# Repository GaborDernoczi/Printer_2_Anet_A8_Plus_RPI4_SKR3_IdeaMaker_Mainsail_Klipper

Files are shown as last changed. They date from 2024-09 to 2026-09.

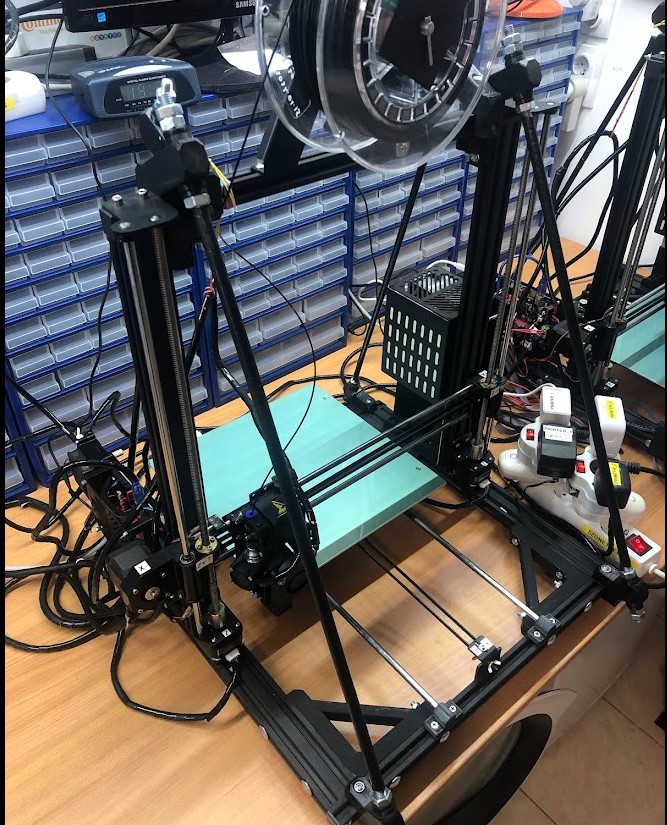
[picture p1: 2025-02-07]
Pictures/Anet_A8_Plus_Printer2_RPI4_SKR3.jpg

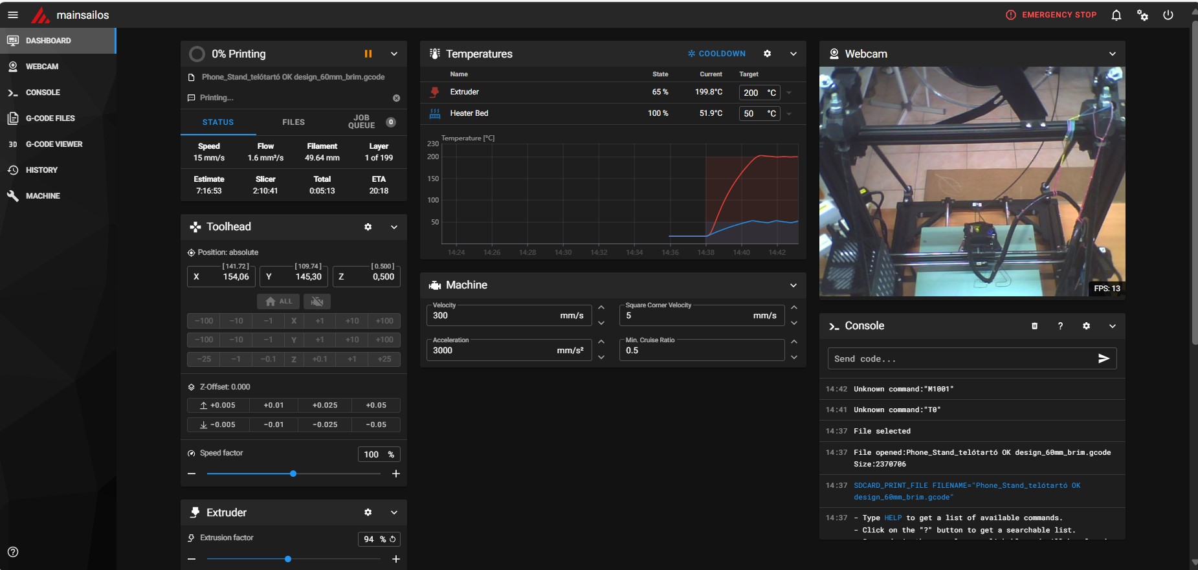
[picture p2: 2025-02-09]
Pictures/Anet_A8_Plus_Printer2_RPI4_Mainsailos.jpg

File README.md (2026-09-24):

# Printer #2 — Anet A8 Plus → Klipper / MainsailOS Conversion

> Converting an Anet A8 Plus from **Marlin + OctoPrint** to **Klipper + Mainsail**, running on a
> Raspberry Pi 4B with a BigTreeTech SKR 3 controller, sliced with the **latest version of
> IdeaMaker** — and fully operable remotely.

This repository is a complete build log and configuration archive. The goal is that the printer
can be **rebuilt from scratch using only the files in this repo**.

---

## Table of Contents

1. [Project Background](#1-project-background)
2. [System Architecture](#2-system-architecture)
3. [Remote Operation](#3-remote-operation)
4. [Hardware](#4-hardware)
5. [Repository Structure](#5-repository-structure)
6. [Rebuild Guide](#6-rebuild-guide)
7. [Key Configuration Values](#7-key-configuration-values)
8. [IdeaMaker Slicer Setup](#8-ideamaker-slicer-setup)
9. [Calibration Results](#9-calibration-results)
10. [Printed Upgrade Parts](#10-printed-upgrade-parts)
11. [References](#11-references)

---

## 1. Project Background

Printer #1 originally ran **Marlin firmware with OctoPrint**. It suffered from recurring problems:

- Inconsistent **bed adhesion**
- Unstable **temperature control**
- Poor and inconsistent print quality, leading to frequent failed prints
- Repeated bed-height calibration did not solve the underlying issues

The printer now runs independently on its own Raspberry Pi and Mainsail instance. The Pi is
reachable on the local network as `pi1` (the presentation records `192.168.0.127` as the example
address; use the current DHCP reservation in your network).

### Outcome

After the conversion the printer has been running **stably**, with no further adhesion or
temperature problems, and significantly improved print performance. Dimensional accuracy was then
dialled in through a documented calibration cycle (see section 9), and the whole workflow — from
slicing to starting the print — became operable without physically touching the machine
(see section 3).

---

## 2. System Architecture

```mermaid
flowchart LR
    PC["Workstation<br/>IdeaMaker slicer"]
    WEB["Browser<br/>Mainsail UI"]
    RPI["Raspberry Pi 4B<br/>MainsailOS<br/>hostname: pi1"]
    KLIPPY["Klippy host process<br/>+ Moonraker API"]
    SKR["BTT SKR 3<br/>STM32H743<br/>TMC2209 x4"]
    HW["Steppers · Heaters<br/>Thermistors · BLTouch"]

    PC -->|upload .gcode| WEB
    WEB -->|HTTP / WebSocket :7125| RPI
    RPI --- KLIPPY
    KLIPPY -->|USB serial| SKR
    SKR --> HW
```

**Division of labour:** the Raspberry Pi does all motion planning, kinematics, pressure advance
and bed-mesh compensation. The SKR 3 only executes pre-computed step timings. This is why the
Klipper configuration lives entirely in `printer.cfg` on the Pi, and the firmware on the board
almost never needs reflashing.

---

## 3. Remote Operation

A core goal of the conversion was **full remote control**: the entire chain — workstation, printer
power, slicing, print start and supervision — can be driven without being in the same room as the
machine.

```mermaid
flowchart TD
    U["Operator<br/>(remote / voice)"]
    ALEXA["Amazon Alexa"]
    SON["Sonoff 230 V smart socket"]
    NANO["Arduino Nano<br/>(powered from the socket, 5 V)"]
    REL["Relay module<br/>momentary contact closure"]
    BTN["PC front-panel<br/>PWR_SW header"]
    PCX["Workstation PC<br/>powers on"]
    PWR["Remote mains switch<br/>printer + Raspberry Pi"]
    PRN["Printer + Raspberry Pi<br/>power on"]
    SLICE["IdeaMaker<br/>slice + export G-code"]
    MS["Mainsail<br/>upload + start print"]
    CAM["Webcam via crowsnest<br/>live supervision"]

    U --> ALEXA --> SON --> NANO --> REL --> BTN --> PCX --> SLICE --> MS
    U --> PWR --> PRN --> MS
    MS --> CAM --> U
```

### Remote power-on of the workstation

The PC is **not** started with Wake-on-LAN. Instead it is started by physically pressing its own
power button, electrically:

1. The operator issues a switch-on command to **Amazon Alexa** (voice or app).
2. Alexa switches on a **Sonoff 230 V smart socket**.
3. The socket feeds an **Arduino Nano**, which therefore boots the moment mains power appears.
4. On start-up the Nano drives a **relay module**.
5. The relay **closes the contacts of the PC's power button** (the `PWR_SW` front-panel header),
   which boots the workstation.

The advantage over Wake-on-LAN is that it is completely independent of the BIOS, the network card,
the operating system and Windows fast-startup. It works even after a full power loss, because it
emulates the same physical action a person would perform.

> **Important:** the relay must produce a **short pulse (roughly 0.3–1 s), not a permanent
> closure.** A continuously held power button is interpreted by the PC as a forced shutdown
> request. The Nano sketch should therefore pulse the relay once after boot and then leave it
> open.

### What each piece does

| Capability | How | Result |
|---|---|---|
| **Start the PC remotely** | Alexa → Sonoff 230 V socket → Arduino Nano (5 V) → relay module → PC power-button contacts | The slicing machine is brought up on demand; no need to leave it running |
| **Start the printer remotely** | Remotely switchable mains power feeding the printer and the Pi | The machine stays powered down between jobs and is energised only when a print is planned |
| **Slice remotely** | Remote desktop onto the workstation, IdeaMaker running there | The slicer profile lives on one machine only — no profile drift |
| **Upload and start** | Mainsail web UI / Moonraker API on port 7125 | Upload `.gcode`, start, pause, cancel, tune live |
| **Watch the print** | `crowsnest` webcam stream embedded in Mainsail | Visual confirmation of the first layer and of progress |
| **Timelapse** | `moonraker-timelapse` (`timelapse.cfg`) | Automatic video of completed prints |

### Why the printer is kept unpowered between jobs

Leaving a heated-bed printer permanently energised is the main fire-risk scenario in a home
workshop. Putting the mains feed on a remotely switchable outlet makes the **default state "off"**,
and power is applied only for the duration of a supervised job. The Raspberry Pi boots in under a
minute, so there is no practical downside.

### Requirements and safety rules

- **Pulse, do not hold, the PC power button.** The Arduino Nano must close the relay only
  momentarily after boot; a permanently closed contact forces the PC off instead of on.
- **Use the relay contacts only as a dry switch** across the `PWR_SW` header. Never feed the
  Arduino's 5 V into the header — the relay must isolate the two circuits.
- **Set the PC BIOS "restore on AC power loss" option to "stay off"**, otherwise the machine may
  boot on its own and the relay pulse will shut it down again.
- **Give the Pi and the PC reserved DHCP leases** so their addresses never move.
- **Do not expose Mainsail or Moonraker directly to the internet.** Moonraker has no
  authentication model suitable for public exposure; `moonraker.conf` in this repo trusts private
  LAN ranges only. Reach the printer from outside over a **VPN**.
- **Never start a heater without a working camera view.** Remote power-on combined with an
  unattended thermal fault is precisely the combination to avoid.
- **Always verify the first layer on the camera** before leaving the print unattended.
- Keep a **physically reachable power cut-off**. A remote switch must never be the only way to
  de-energise the printer.

---

## 4. Hardware

| Component | Part | Notes |
|---|---|---|
| Base printer | Anet A8 Plus | 300 × 300 × 300 mm build volume |
| Frame | Reinforced aluminium-extrusion conversion | Diagonal bracing + corner gussets (AM8-style). Replaces the original acrylic frame. |
| Controller | BigTreeTech **SKR 3** | STM32H743 |
| Stepper drivers | **TMC2209** ×4 | UART mode |
| Host | **Raspberry Pi 4B** | MainsailOS |
| Hotend | **Volcano V6** | Custom mounting solution |
| Probe | **BLTouch / 3D Touch** | Automatic bed mesh levelling |
| Power | **External MOSFET** for the heated bed | Offloads bed current from the board |
| Mains control | **Remotely switchable outlet** (smart plug / relay) | Allows the printer to be powered up and down remotely — see section 3 |
| Camera | USB / Pi camera via **crowsnest** | Live view for remote supervision; timelapse support included |
| Slicer host | Workstation PC, started by the Sonoff + Arduino Nano + relay circuit | Runs the latest IdeaMaker; can be started remotely — see section 3 |
| PC remote start | **Sonoff 230 V smart socket** + **Arduino Nano** + **relay module** | Alexa-triggered; the relay shorts the PC power-button contacts |

> **Verify the MCU on the board before building Klipper.** This build uses the STM32H743 variant
> of the SKR 3 and therefore requires the H743 firmware target described below.

---

## 5. Repository Structure

| Path | Contents |
|---|---|
| `Configuration_Mainsail_Klipper/` | `printer.cfg`, `moonraker.conf`, `mainsail.cfg`, `crowsnest.conf`, `sonar.conf`, `timelapse.cfg` — the working Klipper/Moonraker config set |
| `Calibration/` | Calibration models and the `Klipper Calibrations.xlsx` workbook |
| `IdeaMaker_Profiles/` | `Printer2_ANET_A8_Plus_RPI4_SKR3_Ideamaker_Profile.bin`, Start G-code and End G-code |
| `IdeaMaker_Models/` | `.idea` project files and `.3mf` models actually printed on this machine |
| `Consoles_and_Parts/` | STL files for printed upgrade parts (belt tensioners, fan duct, Pi case, spacers) |
| `Pictures/` | Build and diagnostic photos (BLTouch wiring, external MOSFET, printer render, test prints) |
| `SKR3_User manual/` | BigTreeTech SKR 3 user manual PDF |
| `Mainsail and klipper RPI4 SKR3.pptx` | Step-by-step conversion presentation |

---

## 6. Rebuild Guide

### Step 1 — Flash MainsailOS onto the SD card

1. Install **Raspberry Pi Imager**.
2. Choose **Other specific-purpose OS → 3D printing → MainsailOS (64-bit)**.
3. In the Imager's advanced settings, configure **before** writing:
   - **Hostname** — must be unique per printer (this build uses `pi1`)
   - **Wi-Fi SSID + password**
   - **SSH enabled**, username and password
4. Write the image and boot the Pi.

> **Running two printers?** Give each Pi a distinct hostname *and* a reserved (static) DHCP lease
> in the router. Two Pis = two independent Mainsail instances. Mixing them up is the most common
> cause of "I edited the config and nothing changed".

### Step 2 — Build the Klipper firmware for the SKR 3

SSH into the Pi (e.g. with **Tera Term** or any SSH client) and run:

```bash
cd ~/klipper
make menuconfig
```

Select:

| Option | Value |
|---|---|
| Micro-controller Architecture | `STMicroelectronics STM32` |
| Processor model | `STM32H743` |
| Bootloader offset | `128KiB bootloader` |
| Clock reference | `25 MHz crystal` |
| Communication interface | `USB (on PA11/PA12)` |

Then build:

```bash
make clean
make
```

The output is `~/klipper/out/klipper.bin`.

### Step 3 — Flash the board

`make flash` is not used for this SKR 3 setup. Flash via SD card instead:

1. Download `out/klipper.bin` from the Pi (e.g. with **FileZilla** over SFTP).
2. Rename it to **`firmware.bin`**.
3. Copy it to a FAT32 SD card and insert it into the SKR 3.
4. Power the SKR 3 and wait for the board to finish flashing.
5. Power-cycle the board.
6. **Verification:** the file on the SD card is renamed to `firmware.cur`. If it still says
   `firmware.bin`, the flash did not happen — check the card format, the filename and the jumper.

### Step 4 — Find the MCU serial ID

On the Pi:

```bash
ls /dev/serial/by-id/*
```

Copy the returned path into the `[mcu]` section of `printer.cfg`. Example from this build:

```ini
[mcu]
serial: /dev/serial/by-id/usb-Klipper_stm32h743xx_38003A001751313238353730-if00
```

> This ID is **unique to your board** — it will not match the value in this repo. You must
> replace it.

### Step 5 — Upload the configuration

Copy `Configuration_Mainsail_Klipper/printer.cfg` to the Pi, either through the Mainsail
web UI (**Machine** tab) or over SFTP to `~/printer_data/config/`.

Then check `moonraker.conf` — the `[authorization] trusted_clients` list must include your LAN
subnet, otherwise the web UI will refuse the connection.

Restart Klipper from Mainsail (`FIRMWARE_RESTART`).

### Step 6 — Wire and enable the BLTouch

Wiring photos: `Pictures/3d_touch.jpg`, `3d_touch_2.jpg`, `3d_touch_pins.jpg`.

The probe replaces the Z endstop — note that `[stepper_z]` uses
`endstop_pin: probe:z_virtual_endstop`.

### Step 7 — Safety checks before the first print

Run these **in order**, and keep a hand on the power switch:

```gcode
# 1. Thermistors read plausible room temperature?      -> check Mainsail dashboard
# 2. Does the probe deploy/stow?
BLTOUCH_DEBUG COMMAND=pin_down
BLTOUCH_DEBUG COMMAND=pin_up
# 3. Do the axes move the RIGHT way and hit the endstops?
G28
# 4. PID tuning
PID_CALIBRATE HEATER=extruder TARGET=200
PID_CALIBRATE HEATER=heater_bed TARGET=60
SAVE_CONFIG
# 5. Probe Z offset
PROBE_CALIBRATE
SAVE_CONFIG
# 6. Bed mesh
G28
BED_MESH_CALIBRATE
SAVE_CONFIG
```

> `SAVE_CONFIG` **restarts Klipper** — that is normal. It writes results into the auto-generated
> block at the bottom of `printer.cfg`, which **overrides** the values at the top of the file.

### Step 8 — Calibrate the extruder

Mark 120 mm of filament, then extrude 100 mm and measure what is left. `printer.cfg` already
contains `max_extrude_only_distance: 150` specifically to allow the 100 mm test (the Klipper
default of 50 mm is too small).

---

## 7. Key Configuration Values

From `Configuration_Mainsail_Klipper/printer.cfg`:

### Motion

| Setting | Value | Why |
|---|---|---|
| `kinematics` | `cartesian` | |
| `stepper_x` / `stepper_y` `rotation_distance` | **40** | Theoretical value for a 16-tooth GT2 pulley — **do not change** |
| `stepper_z` `rotation_distance` | **8** | TR8×8 lead screw, mathematically exact — **never change** |
| `microsteps` | 16 (all axes) | |
| `position_max` X / Y / Z | 300 / 300 / 300 | |
| `max_velocity` | 300 mm/s | |
| `max_accel` | **1500** mm/s² | Reduced from 3000 to suppress ringing and corner defects |
| `square_corner_velocity` | 5.0 | |
| `max_z_velocity` / `max_z_accel` | 5 / 100 | |

### Extruder

| Setting | Value |
|---|---|
| `rotation_distance` | 33.500 |
| `nozzle_diameter` | 0.400 mm |
| `sensor_type` | EPCOS 100K B57560G104F |
| `max_temp` | 250 °C |
| `max_extrude_only_distance` | 150 mm |
| `pressure_advance` | 0.05 |
| `pressure_advance_smooth_time` | 0.040 |
| TMC2209 `run_current` | 0.600 A |

### Bed & Probe

| Setting | Value |
|---|---|
| `heater_bed` `sensor_type` | Generic 3950 |
| BLTouch `x_offset` / `y_offset` | **−30 / −25** |
| BLTouch `z_offset` | 2.15 |
| `samples` / `samples_result` | 2 / average |
| `safe_z_home` `home_xy_position` | 150, 150 (bed centre) |
| `bed_mesh` area | 35,30 → 280,280 |
| `bed_mesh` `probe_count` | 5 × 5, bicubic |
| XY/Z TMC2209 `run_current` | 0.800 A |

### SKR 3 specifics

```ini
# The SKR 3 pin mapping and TMC2209 UART pins are defined in printer.cfg.
# The board uses the STM32H743 MCU target selected in make menuconfig.
```

Forgetting this block is the classic "motors do nothing and there is no error message" failure on
the SKR 3.

---

## 8. IdeaMaker Slicer Setup

The slicer belonging to this printer is **IdeaMaker, latest version** (Raise3D). It is free, and
the profile stored in this repository is maintained against the current release — download it from
<https://www.raise3d.com/ideamaker/>.

Copy the contents of `IdeaMaker_Profiles/` into the printer definition in IdeaMaker.

**Start G-code** — homes all axes, moves to a bed-edge reference point, sets the coordinate zero
and performs a slow Z touch-off before lifting and priming.

**End G-code** — turns off both heaters, retracts in two stages while lifting Z, and disables the
steppers.

**Acceleration and Jerk are deliberately disabled in the slicer.** Klipper handles motion planning
itself, and letting the slicer inject `M204`/`M205` would fight the `max_accel` and
`square_corner_velocity` settings in `printer.cfg`.

The full profile is documented as screenshots in
`IdeaMaker_Profiles/Printer2_ANET_A8_Plus_RPI4_SKR3_Ideamaker_Profile.bin`.

---

## 9. Calibration Results

Test object: **50 × 50 × 50 mm** calibration cube. Full narrative in
[Calibration/Calibration_log_EN.txt](Calibration/Calibration_log_EN.txt) (Hungarian version:
[Kalibracios_naplo_HU.txt](Calibration/Kalibracios_naplo_HU.txt)).

| Test | X (mm) | Y (mm) | Z (mm) | Key settings |
|---|---|---|---|---|
| #1 | 48.63 (−1.37) | 49.76 (−0.24) | 50.21 (+0.21) | X rot.dist 40.9, z_offset 1.15, no PA, accel 3000 |
| #2 | 49.74 (−0.26) | 49.79 (−0.21) | 50.17 (+0.17) | X rot.dist **40** (fixed), PA 0.05, accel 1500 |
| #3 | **49.94** (−0.06) | **49.97** (−0.03) | **50.06** (+0.06) | z_offset 2.15 |

All three axes are now within **0.1 mm** (≈0.1 %).

### Lessons recorded

- **The X error was not mechanical.** A −2.74 % deviation looked like a loose belt, but solving
  `measured = 50 × RD_actual / RD_configured` for both axes gave nearly identical results
  (39.78 vs 39.81), proving the fault was the mistyped `rotation_distance` used during the
  earlier calibration attempt.
- **Z height error does not come from `rotation_distance`.** With a TR8×8 screw the value 8 is
  exact. From the second layer onward every layer is correct — *all* height error is created in
  the **first layer**. The fix is always the probe `z_offset`.
- **Klipper sign rule:** a *larger* `z_offset` = nozzle *closer* to the bed = more squish =
  *shorter* part.
- **`SAVE_CONFIG` wins.** Once it has run, the value at the top of `printer.cfg` is ignored. To
  edit manually you must first delete the corresponding lines from the `#*#` block, then run
  `FIRMWARE_RESTART`.
- **A Z value below −4 shown in Mainsail is the head *position*, not the offset.** The dashboard
  live-adjust field and the `PROBE_CALIBRATE` panel are two different things. If you see this
  before a move — stop.

---

## 10. Printed Upgrade Parts

STLs in `Consoles_and_Parts/`:

| File | Purpose |
|---|---|
| `belt_tensioner_A2.stl`, `belt_tensioner_B2.stl` | Belt tensioners (see `belt_tensioner.png`, `beltA2.png`, `beltB2.png`) |
| `Fan_Nozzle_V2.stl` | Part-cooling fan duct |
| `Spacer_for_extruder_part.stl` | Extruder mounting spacer |
| `anet_tavtarto_63mm.stl` | 63 mm Anet spacer |
| `Rpi_4_Case_Bottom.stl` / `_Top.stl` | Raspberry Pi enclosure (plus HDMI-cable variants) |

---

## 11. References

- Klipper documentation — <https://www.klipper3d.org/>
- Pressure Advance tuning — <https://www.klipper3d.org/Pressure_Advance.html>
- Mainsail — <https://docs.mainsail.xyz/>
- MainsailOS — <https://docs.mainsail.xyz/setup/mainsail-os>
- SKR 3 documentation — `SKR3_User manual/BIGTREETECH SKR 3 user manual.pdf`
- Conversion presentation — `Mainsail and klipper RPI4 SKR3.pptx`

### Tools used

| Tool | Role |
|---|---|
| Raspberry Pi Imager | Write MainsailOS to SD |
| FileZilla | SFTP transfer of `klipper.bin` and `printer.cfg` |
| Tera Term | SSH session to the Pi |
| **IdeaMaker (latest version)** | Slicer |
| Mainsail | Web interface and remote print control |
| Alexa + Sonoff 230 V socket | Remote power-on of the workstation (via Arduino Nano + relay) |
| Arduino IDE | Sketch for the Nano that pulses the relay on boot |
| Remote mains switch | Remote power-on of the printer |

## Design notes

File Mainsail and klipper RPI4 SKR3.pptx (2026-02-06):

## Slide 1

Install mainsailos on raspberry 4 with raspberry imager, SD card.

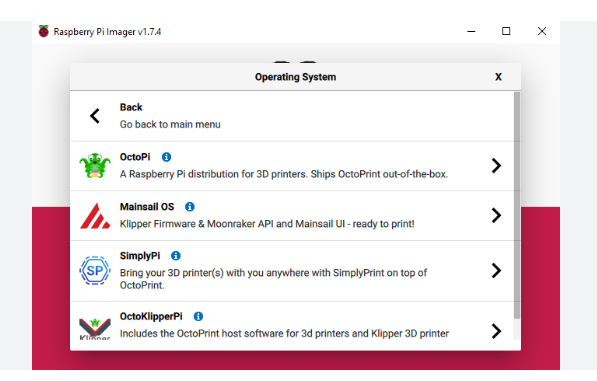
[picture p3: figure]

Set wifi and password etc

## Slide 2

ssh pi@mainsailos.local
cd klipper
make menuconfig

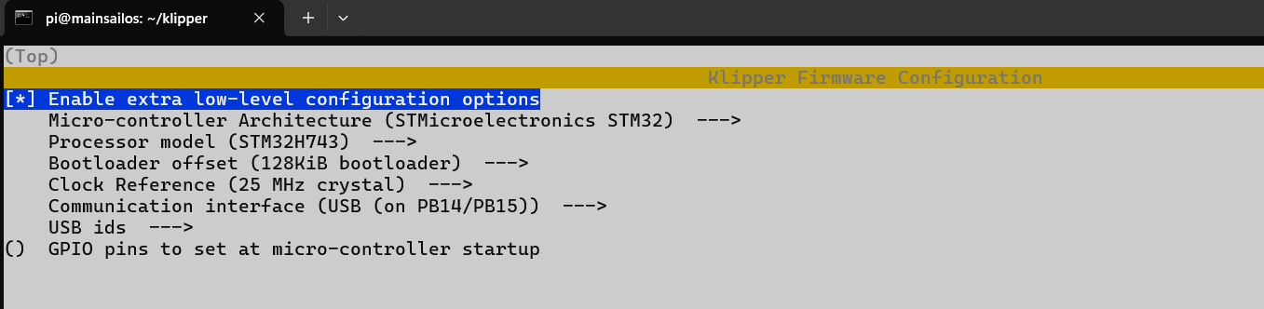
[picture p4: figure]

Make -> klipper.bin

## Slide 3

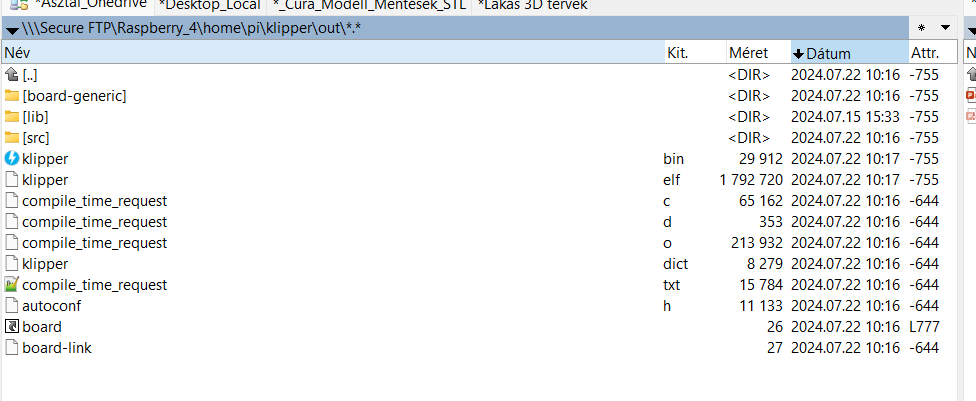
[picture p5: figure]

Rename Klipper.bin to firmware.bin and copy SD card ->power on SKR3
Get firmware.cur

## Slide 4

lsusb

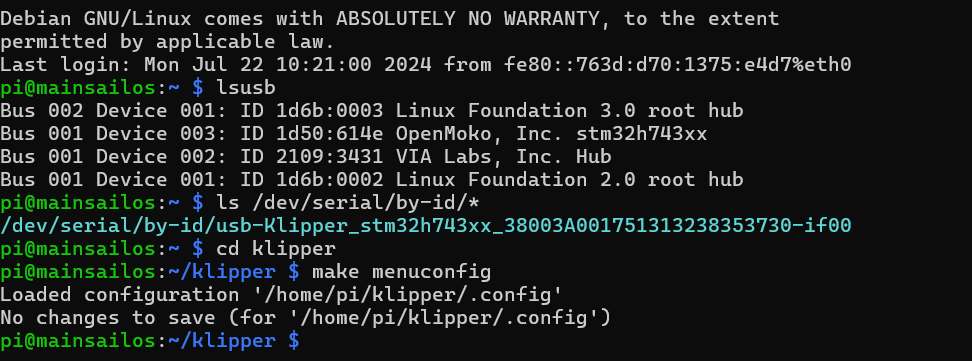
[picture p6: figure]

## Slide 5

Create printer.cfg-t in mainsail

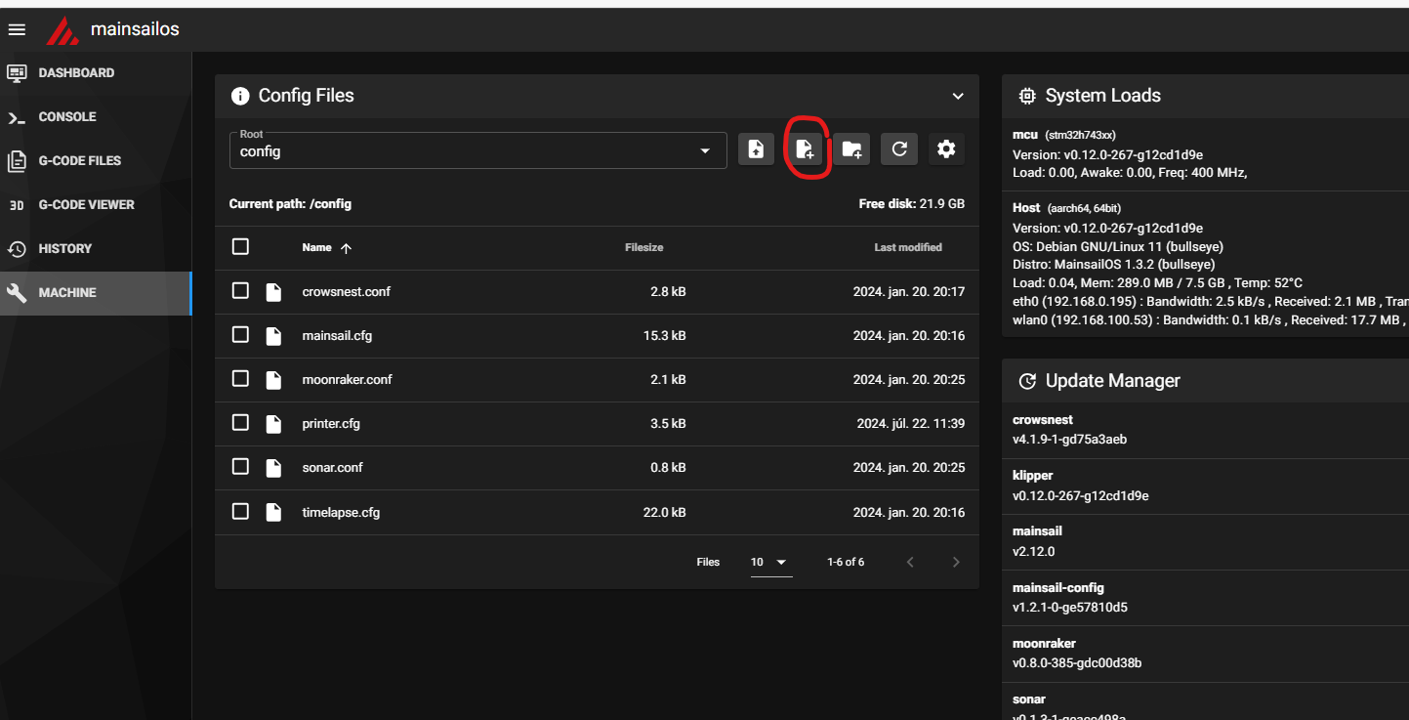
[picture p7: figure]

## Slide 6

Copy usb address to printer.cfg

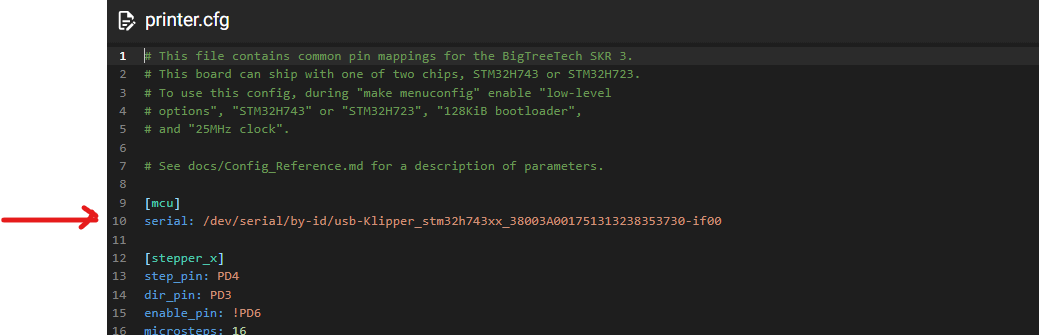
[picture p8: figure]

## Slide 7

Enable TMC2209 in printer.cfg

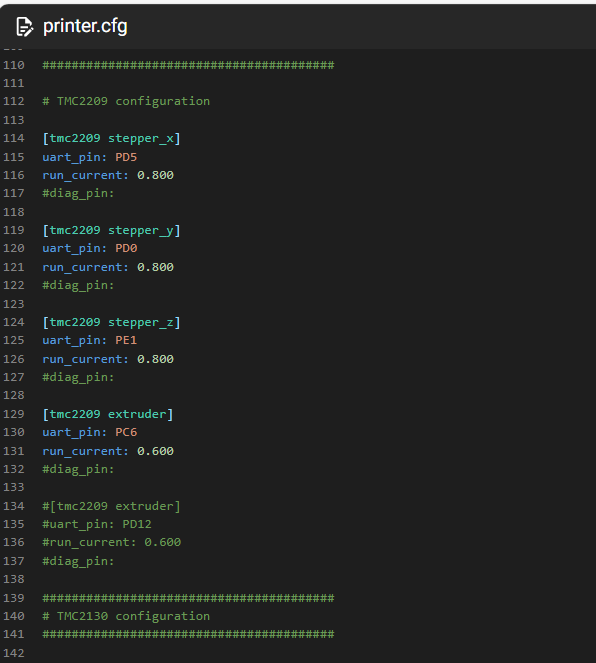
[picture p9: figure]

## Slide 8

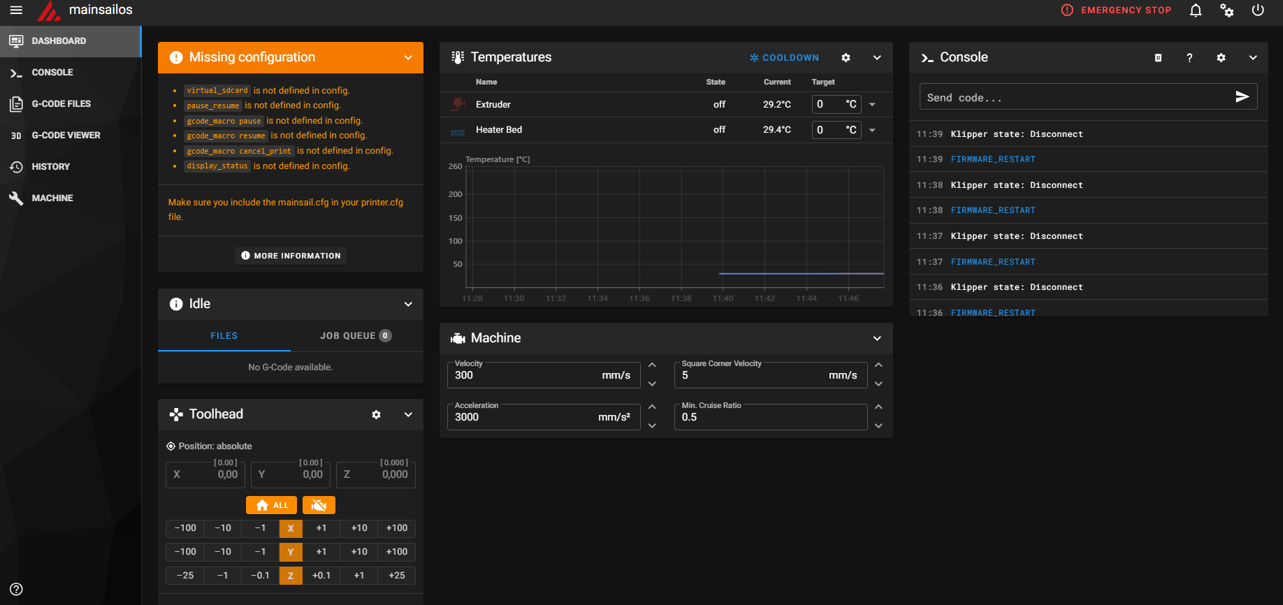
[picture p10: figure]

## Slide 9

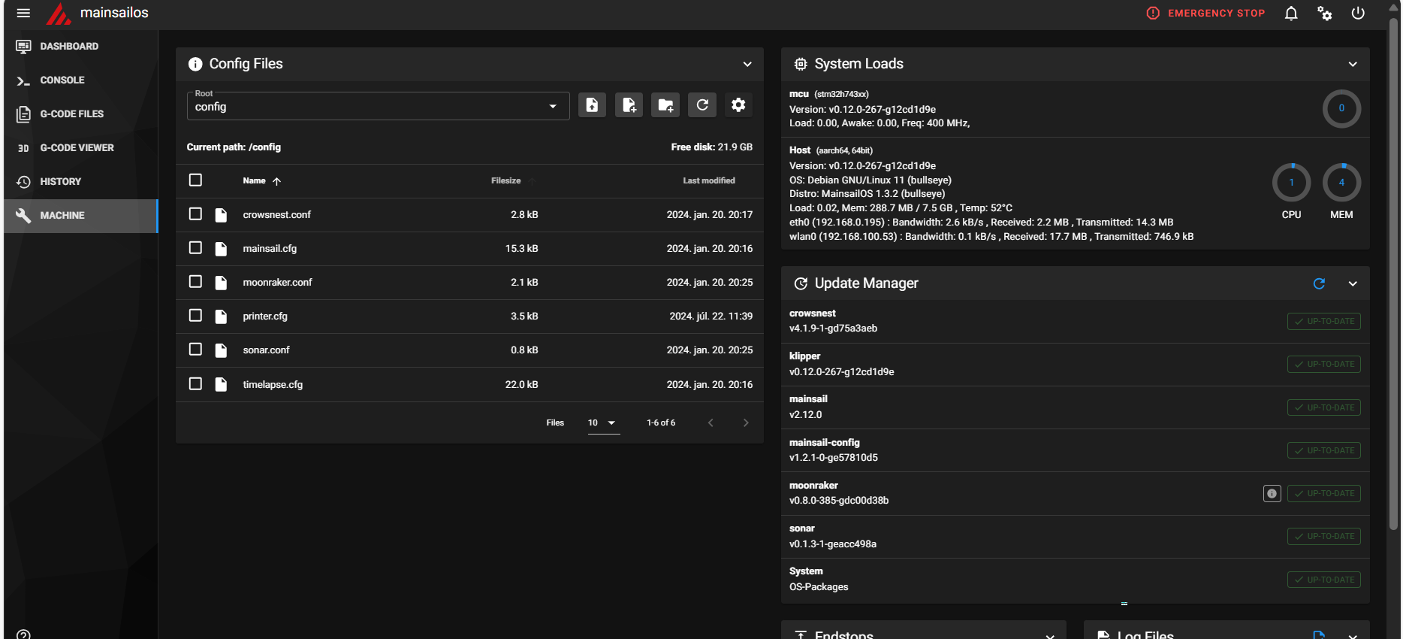
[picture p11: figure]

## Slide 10

Upgrading Anet A8 Plus to Klipper with MainsailOS
Printer #1 with RPI4B+ & SKR3

Download Tera Term and -> host=pi@mainsailos-> 192.168.0.127 -> pi1 and password
Get USB ID: ls /dev/serial/by-id/*

Release Tera Term 5.3 · (https://github.com/TeraTermProject/teraterm/releases/tag/v5.3)TeraTermProject (https://github.com/TeraTermProject/teraterm/releases/tag/v5.3)/ (https://github.com/TeraTermProject/teraterm/releases/tag/v5.3)teraterm (https://github.com/TeraTermProject/teraterm/releases/tag/v5.3)

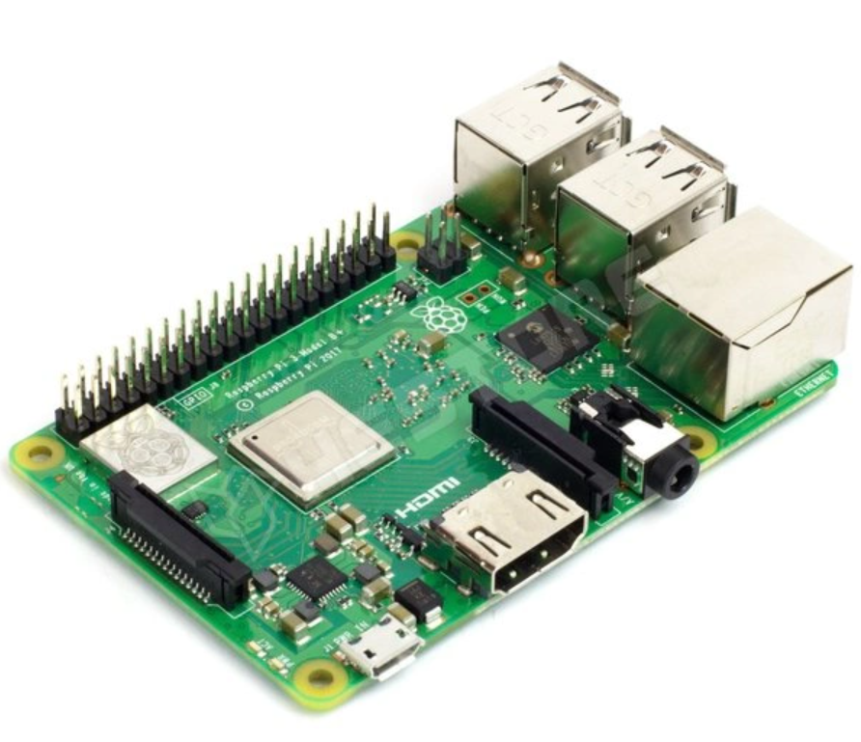
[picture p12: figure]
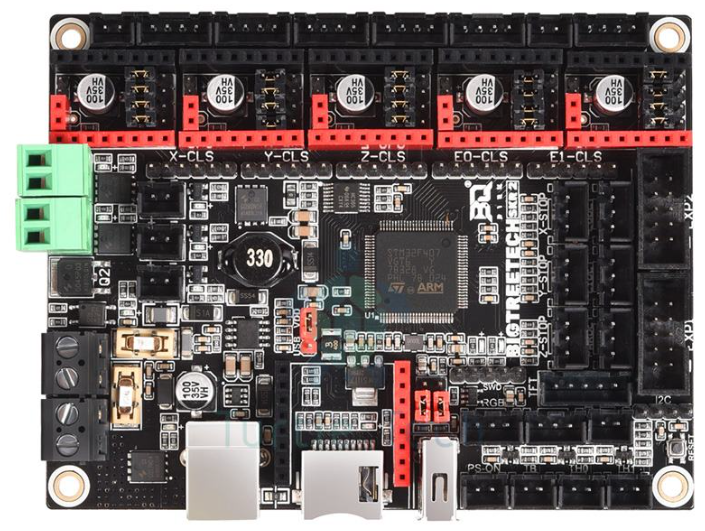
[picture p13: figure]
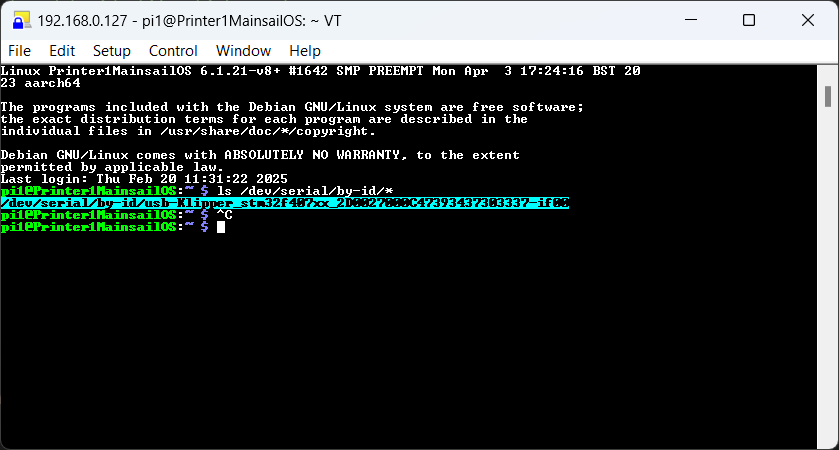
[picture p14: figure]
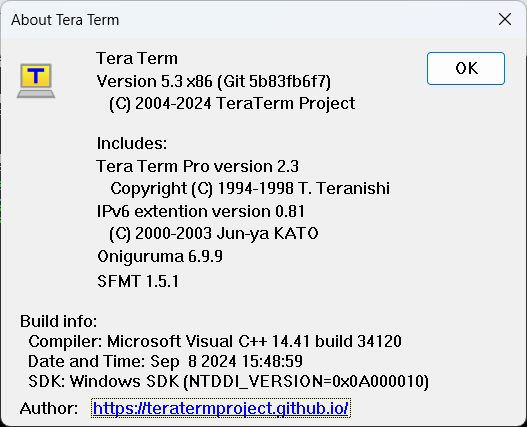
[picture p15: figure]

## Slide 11

Volcano V6 extruder

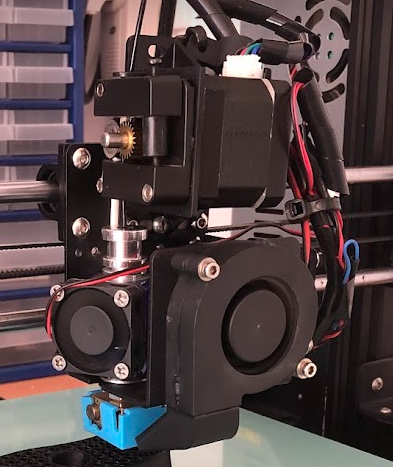
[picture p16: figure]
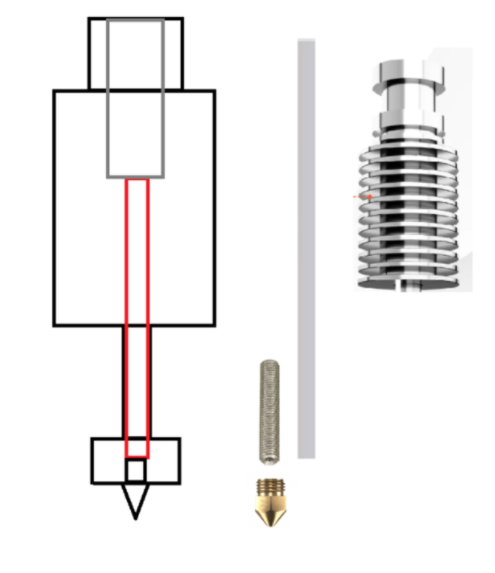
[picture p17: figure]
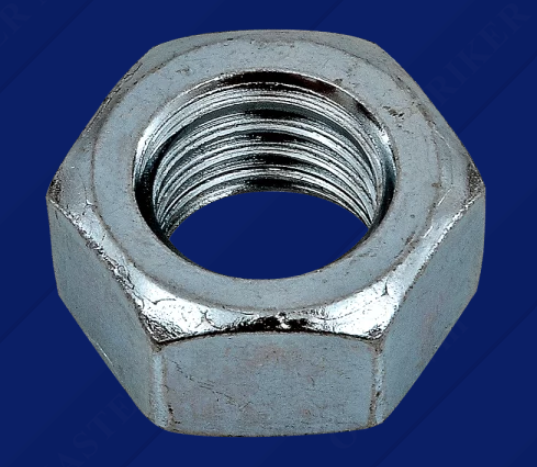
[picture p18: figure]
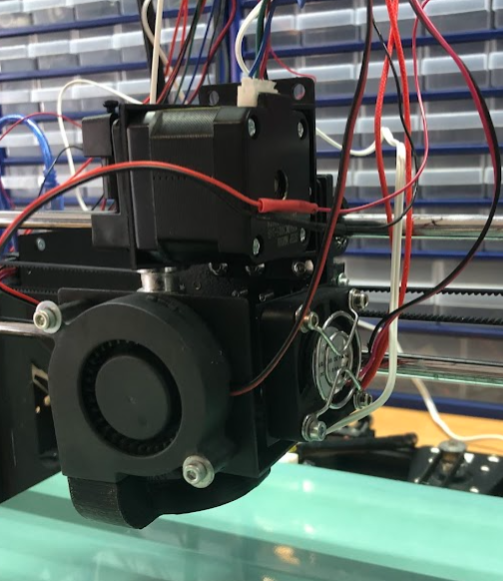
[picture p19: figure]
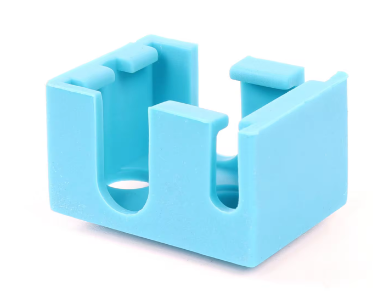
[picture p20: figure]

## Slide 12

IdeaMaker Profile

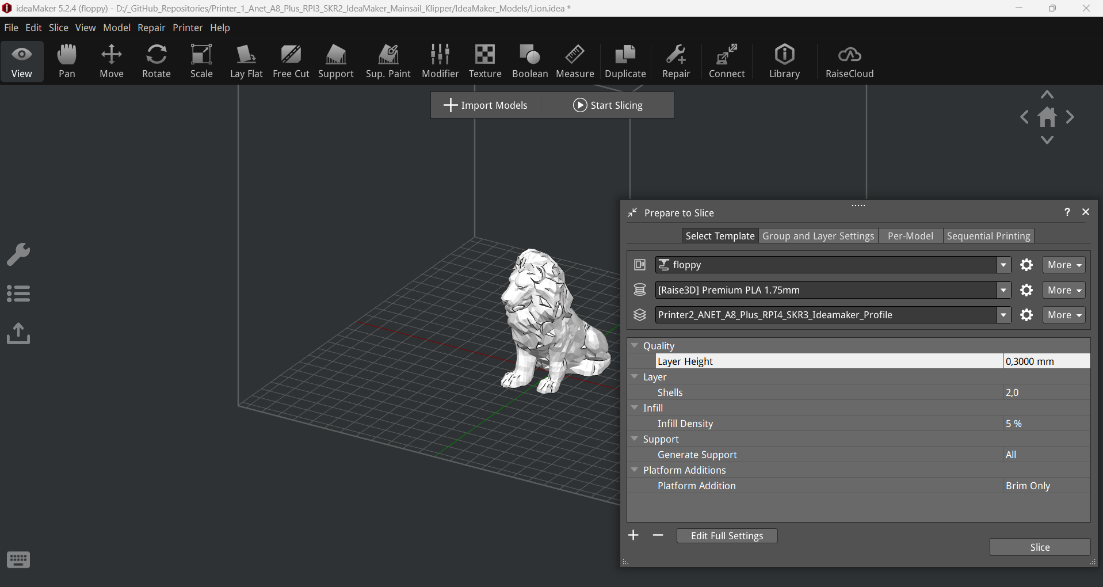
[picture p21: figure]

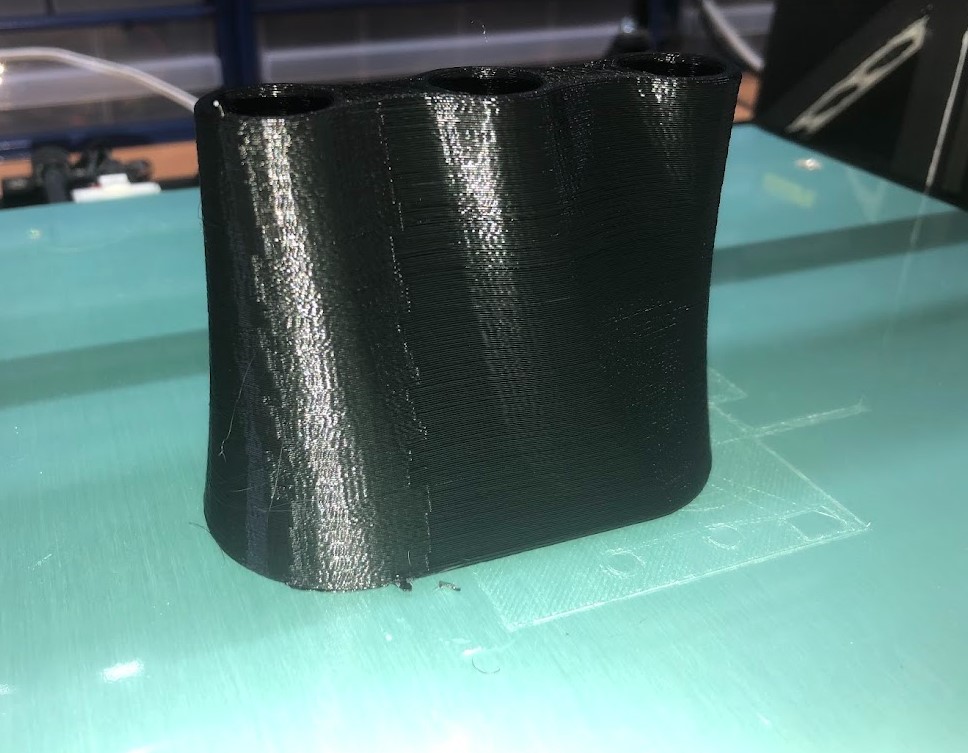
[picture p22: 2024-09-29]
Pictures/Pencil_holder_Black_Front2.jpg

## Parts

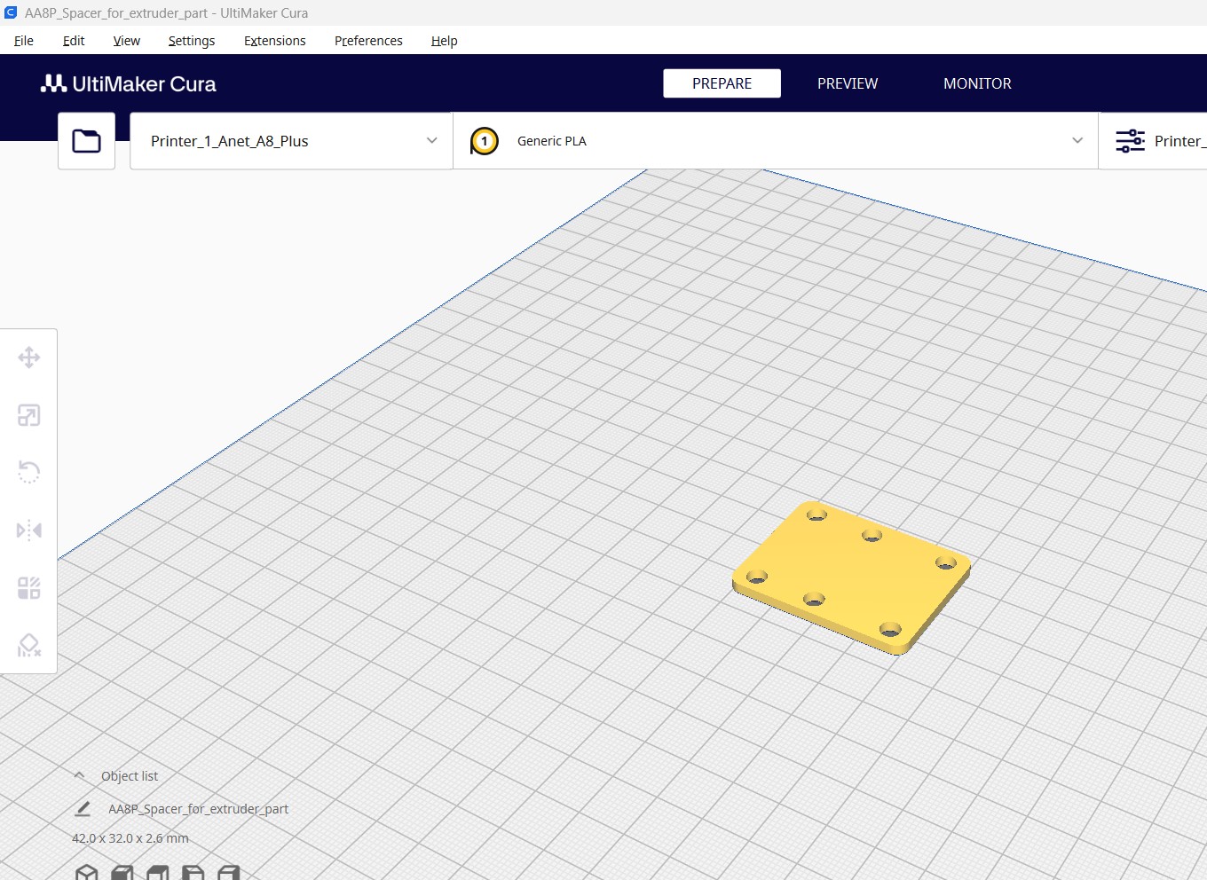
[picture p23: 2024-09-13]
Consoles_and_Parts/Spacer_for_extruder_part.jpg

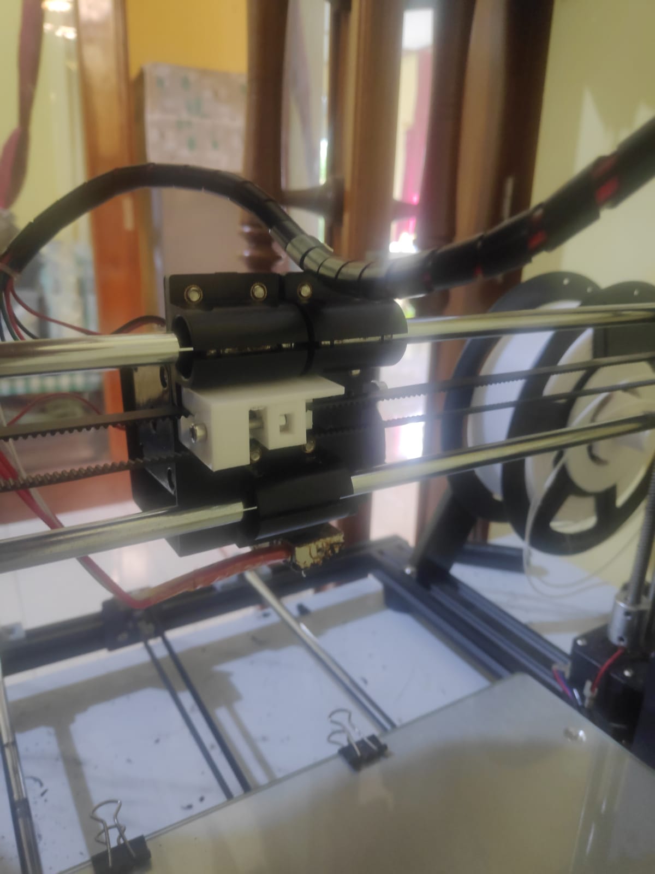
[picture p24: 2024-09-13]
Consoles_and_Parts/belt_tensioner_2.jpg

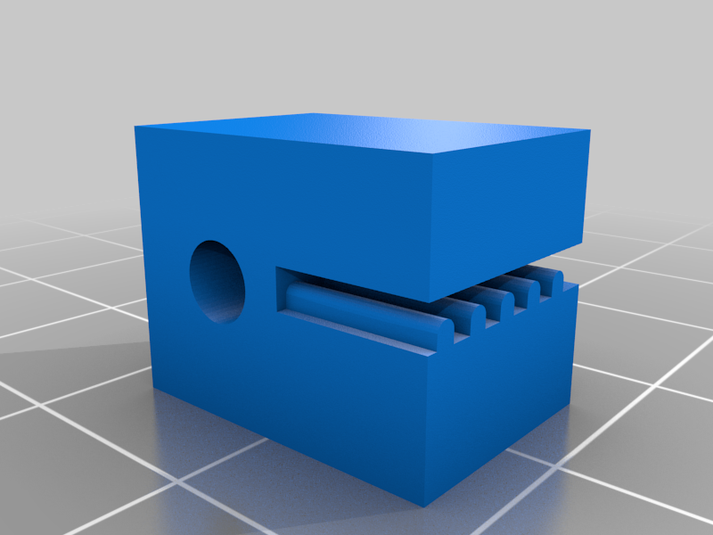
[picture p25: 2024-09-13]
Consoles_and_Parts/beltB2.png

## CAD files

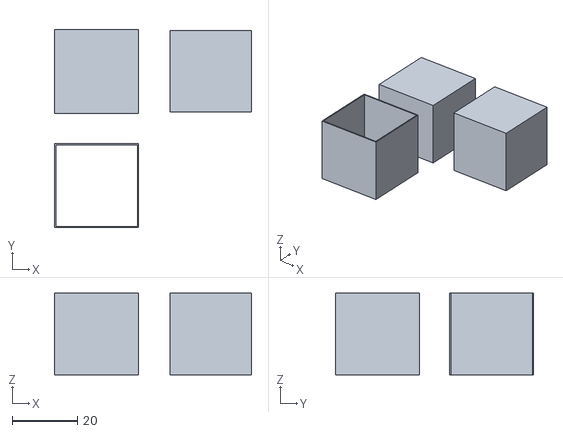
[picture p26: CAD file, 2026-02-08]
Calibration/Calibration_Cubes.STL
60.4 x 60.8 x 25.0

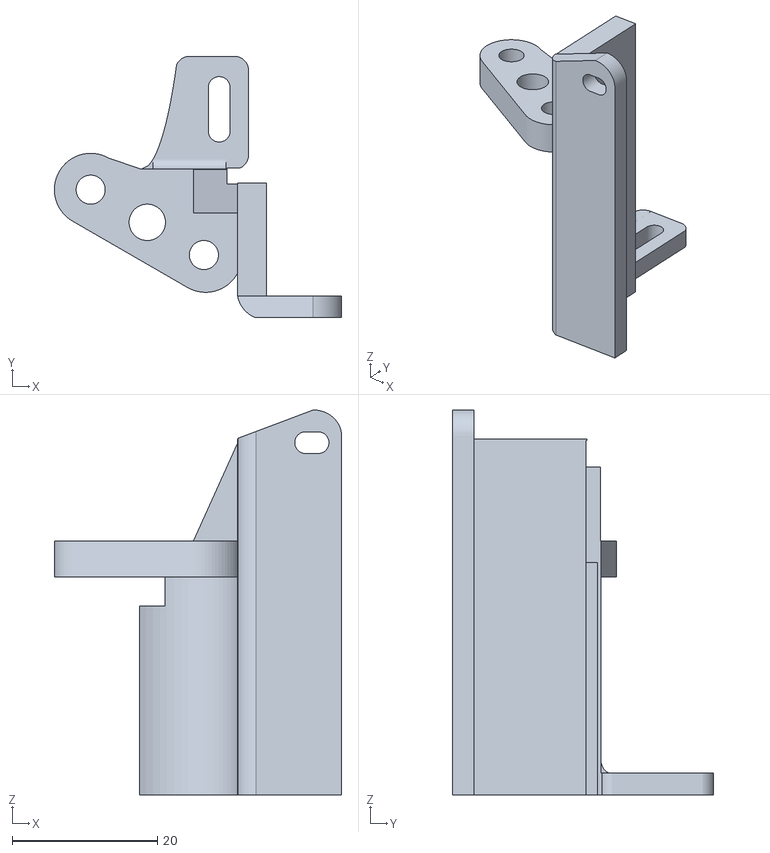
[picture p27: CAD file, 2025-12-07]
Consoles_and_Parts/A8P_BT1.stl
39.5 x 36.0 x 53.0

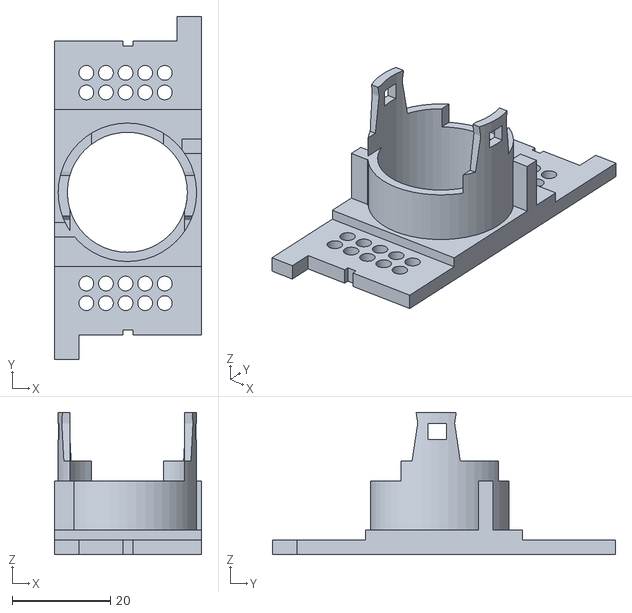
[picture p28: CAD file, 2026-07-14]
IdeaMaker_Models/Adrián/Cool Snicket.stl
30.0 x 70.0 x 29.0

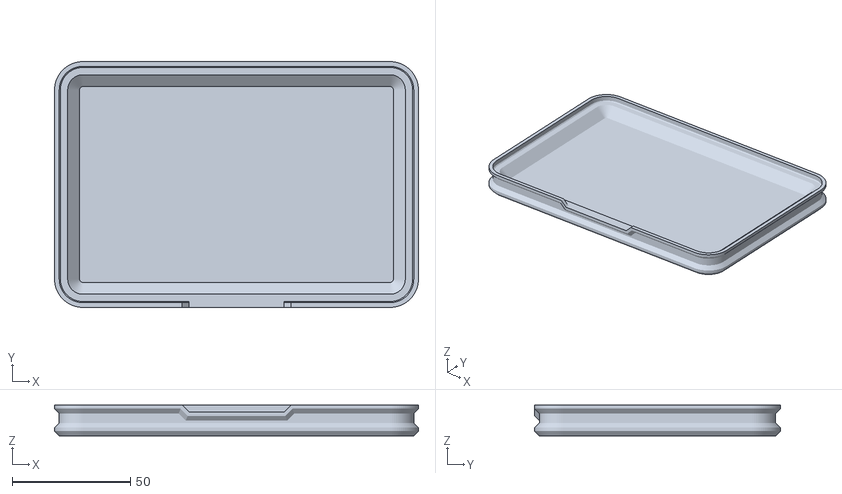
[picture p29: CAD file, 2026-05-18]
IdeaMaker_Models/Coffee_Tea+base_/obj_2_Body1.stl
154.0 x 104.0 x 13.0

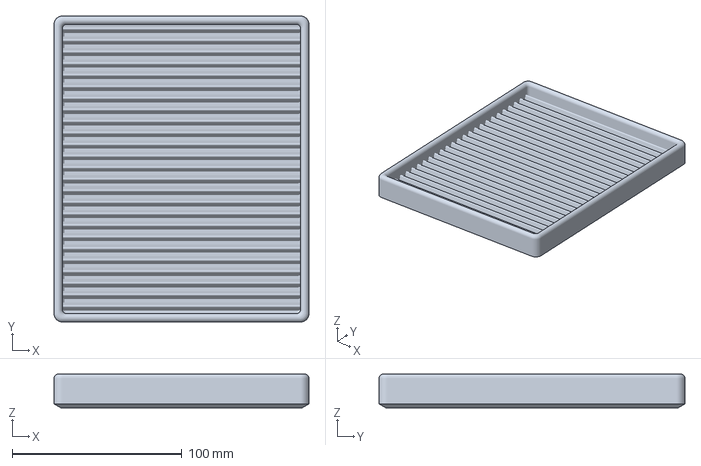
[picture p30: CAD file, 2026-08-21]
IdeaMaker_Models/Drip+Tray+-+180x150mm.3mf
150.0 x 180.0 x 20.0 mm

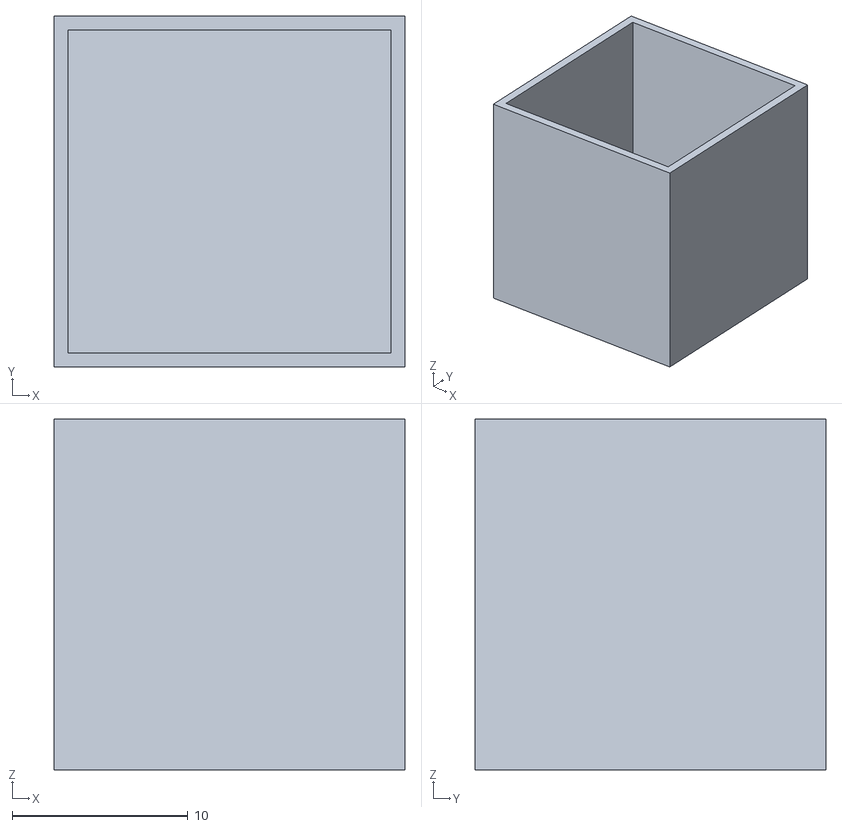
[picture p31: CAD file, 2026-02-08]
Calibration/FlowCalibrationCube4mm_nozzle0.8walls.stl
20.0 x 20.0 x 20.0

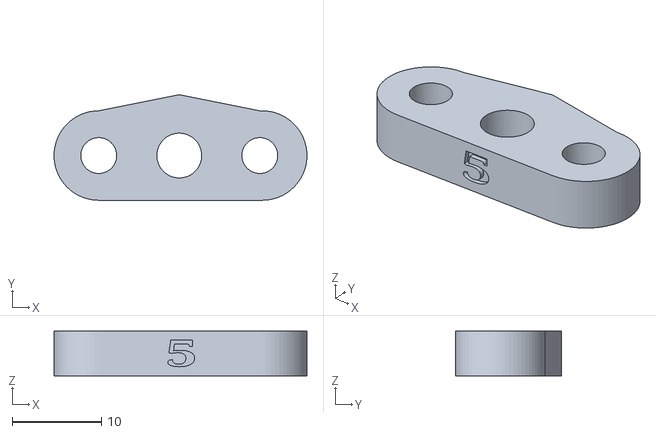
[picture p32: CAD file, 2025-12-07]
Consoles_and_Parts/A8P_BTbetet5.stl
28.3 x 11.8 x 5.00

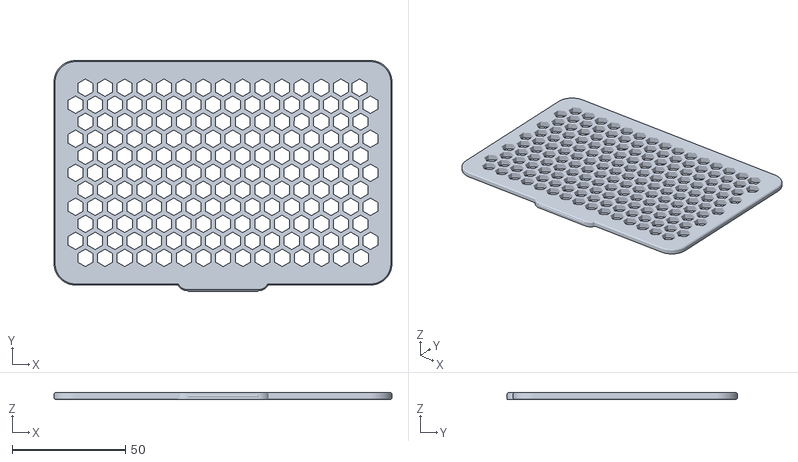
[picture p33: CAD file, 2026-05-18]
IdeaMaker_Models/Coffee_Tea+base_/obj_1_Body2.stl
149.0 x 101.8 x 3.00

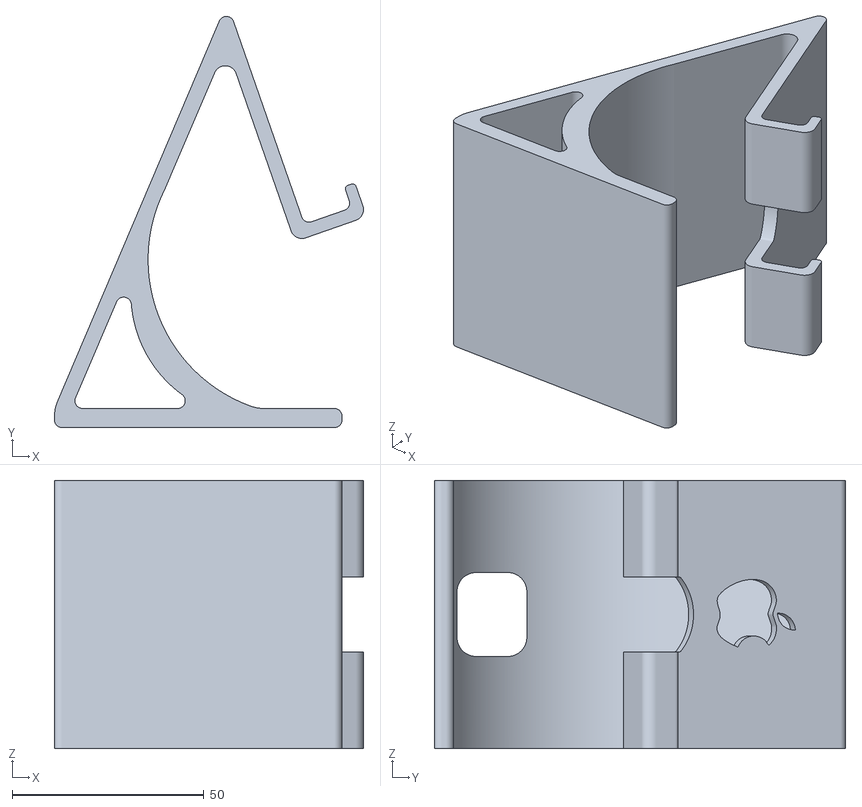
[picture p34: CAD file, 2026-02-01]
IdeaMaker_Models/p2_iPhoneStand.STL
80.6 x 107.3 x 70.0

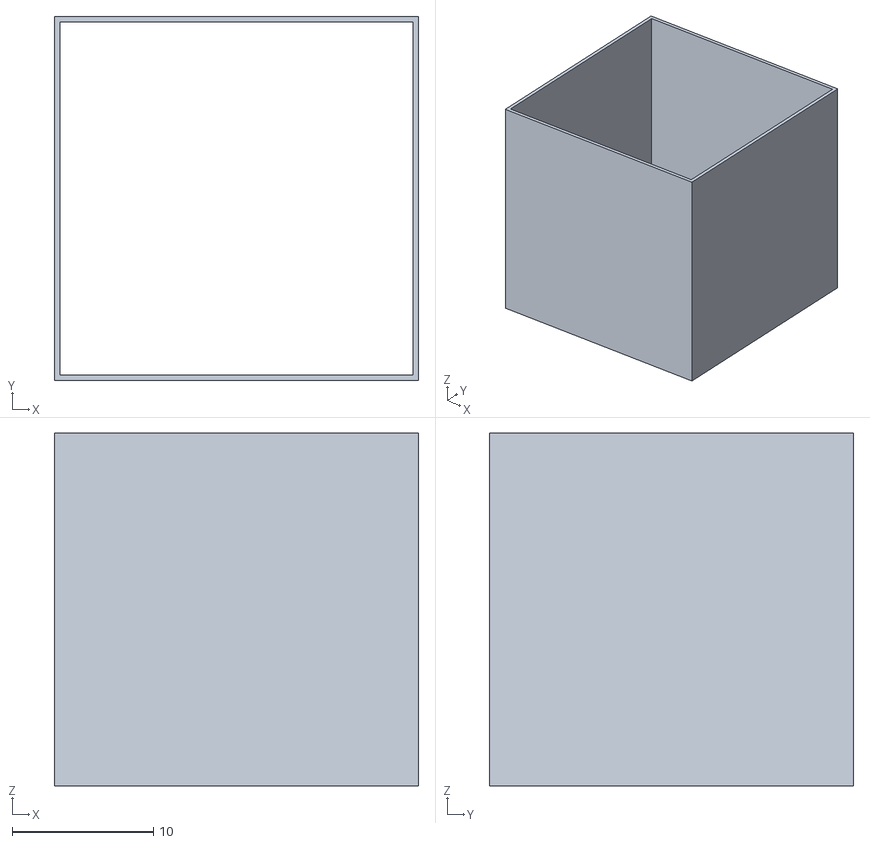
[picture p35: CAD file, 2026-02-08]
Calibration/TW_Calibration_Cubes.STL
25.8 x 25.8 x 25.0

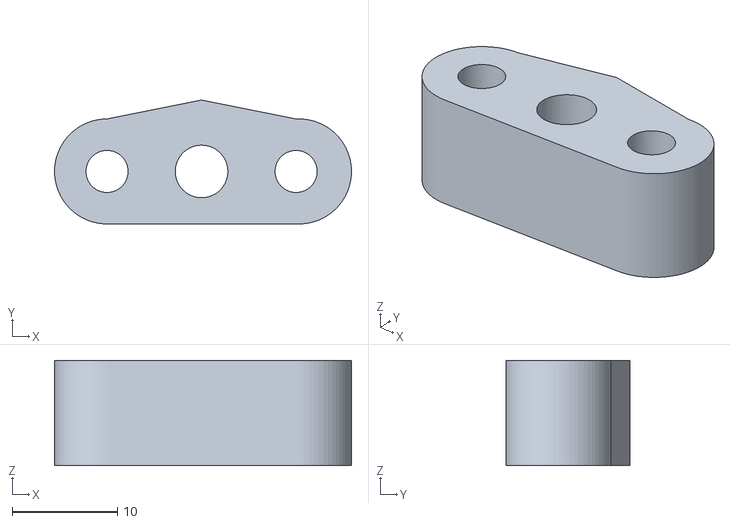
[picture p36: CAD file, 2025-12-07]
Consoles_and_Parts/A8P_BTbetet10.stl
28.3 x 11.8 x 10.00

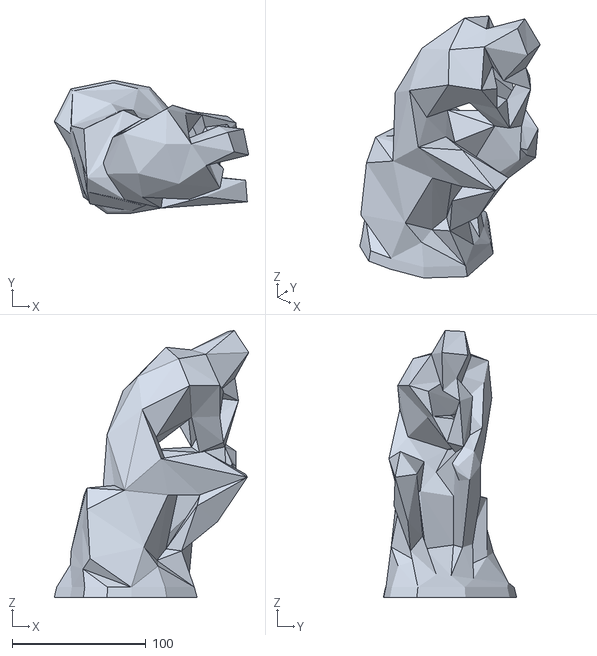
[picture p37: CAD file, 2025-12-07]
IdeaMaker_Models/Lowest_poly_thinker_easier_to_print.stl
145.7 x 100.0 x 200.0

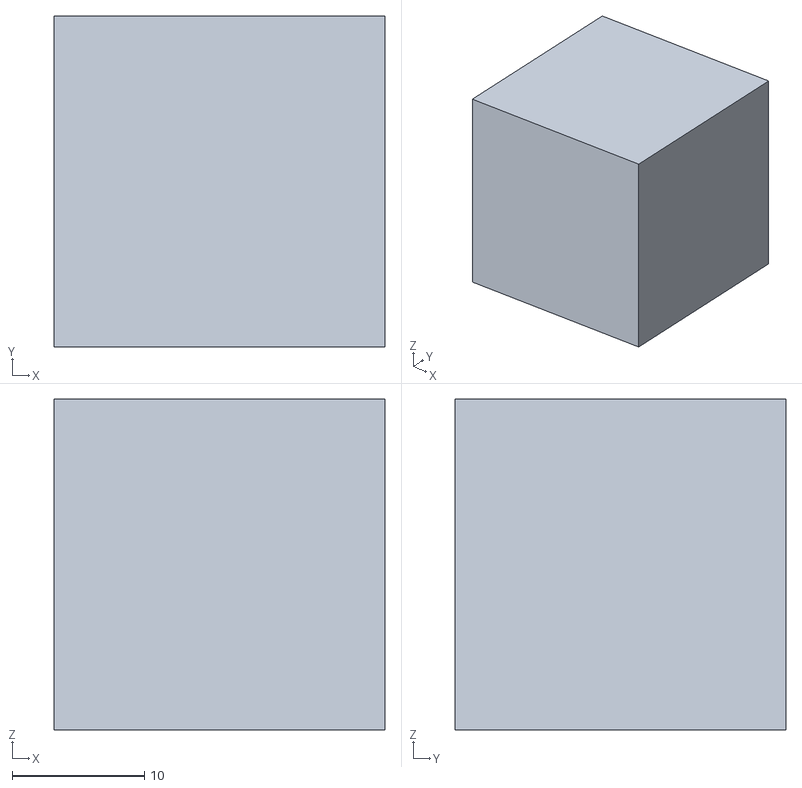
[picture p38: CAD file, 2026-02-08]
Calibration/SLD_Calibration_Cubes.STL
25.0 x 25.0 x 25.0

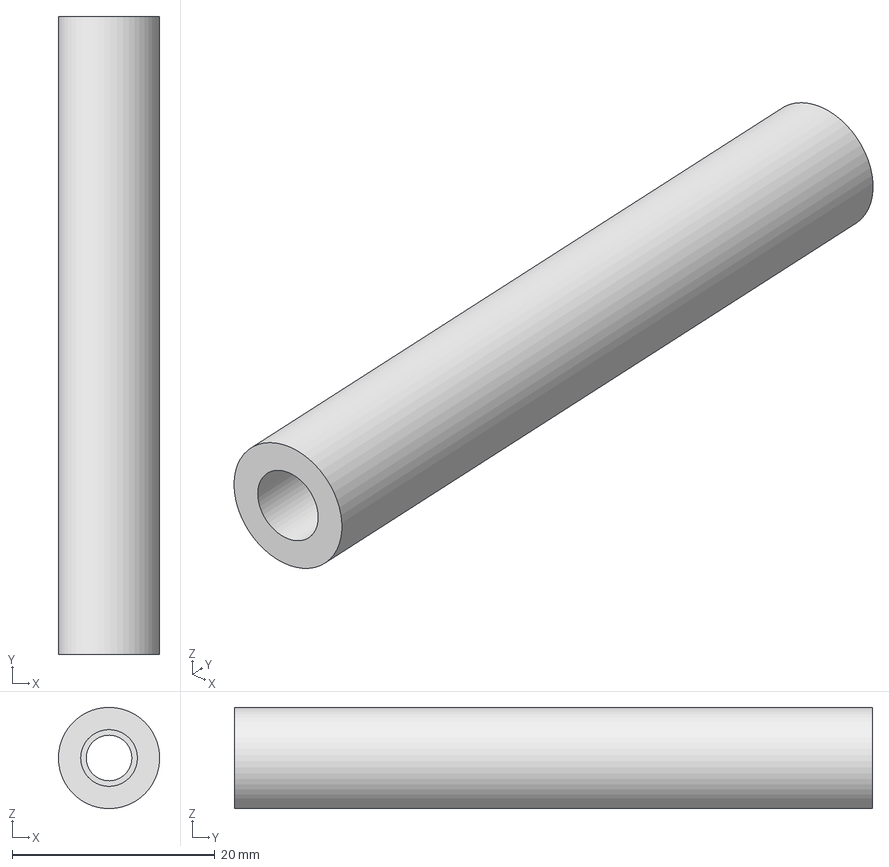
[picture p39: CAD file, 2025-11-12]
Consoles_and_Parts/anet_extruder_tavtarto_63mm.stp
9.99 x 63.0 x 10.00 mm

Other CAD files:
IdeaMaker_Models/yellowcat.stl
Calibration/BRG_Calibration_Cubes.STL
Consoles_and_Parts/BL touch Anet__A8_Version.stl
IdeaMaker_Models/Kobra3_Camera3.3mf
Calibration/Pz_xyz_calibration_cube_v1.stl
Consoles_and_Parts/BL_touch_Anet_A8_plus_mount_remix.stl
Consoles_and_Parts/Dial.stl
Consoles_and_Parts/DialHolder.stl
Consoles_and_Parts/Fan_Nozzle_V2.stl
Consoles_and_Parts/Rpi_4_Case_Bottom.stl
Consoles_and_Parts/Rpi_4_Case_Bottom_official_rPI_HDMI_cable.stl
Consoles_and_Parts/Rpi_4_Case_Top.stl
Consoles_and_Parts/Rpi_4_Case_Top_official_rPI_HDMI_cable.stl
Consoles_and_Parts/Spacer_for_extruder_part.stl
Consoles_and_Parts/SwitchHolder.stl
Consoles_and_Parts/ZEndCap.stl
Consoles_and_Parts/anet_extruder_tavtarto_63mm.stl
Consoles_and_Parts/belt_tensioner_A2.stl
Consoles_and_Parts/belt_tensioner_B2.stl
IdeaMaker_Models/CHEPCalibrationCube.stl
IdeaMaker_Models/Capybara_PHONE_15mm.stl
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

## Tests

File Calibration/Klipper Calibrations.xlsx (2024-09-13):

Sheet: INSTRUCTIONS
To Use the Spreadsheet Go to "File" -> "Make a Copy"
You can also try my Klipper Calibration website:
Minilam3DP Klipper Calibration Website: https://minimal3dp.com/ | minimal3dp@gmail.com
Minimal 3Dp on Youtube | Minimal 3DP (https://www.youtube.com/channel/UCM_8Mv-0S1LnnJpRJLjahaw?sub_confirmation=1)
Try My Klipper Calibration Website | Klipper Calibration Website (https://minimal3dp.com/klipper-calibration/)
TABS AT BOTTOM FOR VARIOUS TESTS
↓

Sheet: Extruder Rotation Distance
Extruder Rotation Distance
Video Guide
References: | Rotation distance - Klipper documentation (https://www.klipper3d.org/Rotation_Distance.html)
 | Klipper Extruder Rotation Distance Calculator | 3D Print Beginner (https://3dprintbeginner.com/rotation-distance-calculator/)
Legend: |  |  | Variables:
 | DO NOT EDIT |  | Full Steps Per Rotation | 1.8 Stepper | 200
 | Edit to Suit |  | Full Steps Per Rotation | .9 Stepper | 400
 | User Input |  |  | Micro Steps | 32
E-Steps and Rotation Distance Calculations
Rotation Distance = | Full Steps Per Rotation * | Micro Steps / | E Steps
16 | 200 | 32 | 400
E-Steps = | Full Steps Per Rotation * | Micro Steps / | Rotation Distance
800 | 200 | 32 | 8
Measure and Trim | Rotation distance - Klipper documentation (https://www.klipper3d.org/Rotation_Distance.html)
initial_mark_distance | 70 | mm
requested_extrude_distance | 50 | mm
Console Commands:
 | G91
 | G1 E50 F60 | E## = requested_extrude_distance
actual_extrude_distance = | initial_mark_distance | - subsequent_mark_distance
49.51 | 70 | 20.49
Rotation Distance = | previous_rotation_distance | * actual_extrude_distance | / requested_extrude_distance
24.235 | 24.475 | 49.51 | 50

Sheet: Flow Calibration
Flow Calibration | Not Recommended
Video Guide
References: | https://3dprintbeginner.com/flow-rate-calibration/
 | https://3dprinterly.com/how-to-calibrate-your-extruder-e-steps-flow-rate/
Legend:
 | DO NOT EDIT
 | Edit to Suit
 | User Input
Slicer Settings:
Layer Height | 0.2
Perimeters | 2
Line Width | 0.5
Print Thin Walls | Off
Top Layer | 0
Bottom Layer | 1
Infill | 0%
Cube STL File: | Flow_Cube.stl (https://drive.google.com/file/d/11vJEoea94jWu8c0bYwK1tcJ92S1TD9wj/view?usp=sharing)
Steps:
1 | Print Cube with Settings Above
2 | Measure the top of all 4 sides and place values below
3 | Update Flow in Slicer with "FLOW" Value
Nozzle Diameter | 0.4
Measure 1 | 0.930
Measure 2 | 0.950
Measure 3 | 0.950
Measure 4 | 0.960
Average | 0.9475
FLOW Value | 105.541 | %

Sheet: OrcaSlicer Flow Calibration
Orca SlicerFlow | Recommended
Calibration
Video Guide
References: | https://3dprintbeginner.com/flow-rate-calibration/
 | https://3dprinterly.com/how-to-calibrate-your-extruder-e-steps-flow-rate/
Legend:
 | DO NOT EDIT
 | Edit to Suit
 | User Input
Steps:
1 | Orca Slicer -> Calibration -> Flow Rate -> Pass 1
2 | Feel each "Slide" and determine the Smoothest
3 | Update Values Below
Pass 1
Old Flow Rate | 1
Pass 1 Slide Value | -10.000
Pass 1 FLOW Value | 0.900
4 | Complete Pass 2
Pass 2
Pass 1 Flow Rate | 0.900
Pass 2 Slide Value | -1.000
New FLOW Value | 0.891
5 | Use Pass 2 Flow Rate in Slicer

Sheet: Run Current
Run Current for TMC2208/2209
Video Guide
References: | https://docs.vorondesign.com/community/howto/120decibell/calculating_driver_current.html
Legend:
 | DO NOT EDIT
 | Edit to Suit
 | User Input
Peak Current | 1.500 | See Motor Spec Sheet
RMS Factor | 0.707 | See Reference
Run Current | 1 | Update TMC Section of Printer.cfg

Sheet: Pressure Advance
Pressure Advance
Video Guide
References: | https://www.klipper3d.org/Pressure_Advance.html
Legend:
 | DO NOT EDIT
 | Edit to Suit
 | User Input
Nozzle Diameter | 0.4
Layer Height | 0.3
Infill | 0
COMANDS:
Setup | SET_VELOCITY_LIMIT SQUARE_CORNER_VELOCITY=1 ACCEL=500
Direct Drive | TUNING_TOWER COMMAND=SET_PRESSURE_ADVANCE PARAMETER=ADVANCE START=0 FACTOR=.005
Bowden | TUNING_TOWER COMMAND=SET_PRESSURE_ADVANCE PARAMETER=ADVANCE START=0 FACTOR=.020
pressure_advance = <start> + <measured_height> * <factor>
Square Tower | https://www.klipper3d.org/prints/square_tower.stl
Start | 0 | Based on Commands above
Direct Drive Factor | 0.005 | Based on Commands above
Bowden Factor | 0.02 | Based on Commands above
Measured Height | 12.29
Direct Drive Pressure Advance | 0.06145 | Use for Direct Drive
Bowden Pressure Advance | 0.2458 | Use for Bowden

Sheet: PA & OrcaSlicer
Pressure Advance
Video Guide
References: | https://github.com/SoftFever/OrcaSlicer/wiki/Calibration#pressure-advance
Legend:
 | DO NOT EDIT
 | Edit to Suit
 | User Input
PA Tower
Start | 0 | Based on Commands above
Direct Drive Step | 0.002 | Based on Commands above
Bowden Step | 0.02 | Based on Commands above
Measured Height | 30.3
Direct Drive Pressure Advance | 0.0606 | Use for Direct Drive
Bowden Pressure Advance | 0.606 | Use for Bowden

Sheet: Input Shaping
Input Shaping
Video Guide
References: | https://www.klipper3d.org/Resonance_Compensation.html
 | https://all3dp.com/2/klipper-input-shaping-simply-explained/
Legend:
 | DO NOT EDIT
 | Edit to Suit
 | User Input
Slicer Settings:
Layer Height | 0.2 | or .25
Paerimeters | 1 | 0r 2 0r Vase Mode
Line Width | 0.5
Print Speed | 100 | 0r 80
Top Layer | 0
Bottom Layer | 5
Infill | 0%
Cube STL File: | https://www.klipper3d.org/prints/ringing_tower.stl
Steps:
1 | If square_corner_velocity parameter was changed, revert it back to 5.0.
2 | Klipper Console Command:
 | SET_VELOCITY_LIMIT ACCEL_TO_DECEL=7000
3 | Klipper Console Command:
 | SET_PRESSURE_ADVANCE ADVANCE=0
4 | Klipper Console Command:
 | SET_INPUT_SHAPER SHAPER_FREQ_X=0 SHAPER_FREQ_Y=0
5 | Klipper Console Command:
 | TUNING_TOWER COMMAND=SET_VELOCITY_LIMIT PARAMETER=ACCEL START=1500 STEP_DELTA=500 STEP_HEIGHT=5
6 | Print with Settings Above
7 | Count the "rings" on X and Y sides of ringing tower
8 | Measure the distance between Rings
Print Speed | 100 | Based on Commands above
X Rings | 3 | Based on X Ring Count
X Measurements | 14.58 | Based on Caliper Measurements
Y Rings | 6 | Base on Y Ring Count
Y Measurements | 16.75 | Based on Caliper Measurements
X Frequency | 20.576 | Hz
Y Frequency | 35.821 | Hz
Add Below to Printer.cfg with above X and Y Frequencies
[input_shaper]
shaper_freq_x: ... # frequency for the X mark of the test model
shaper_freq_y: ... # frequency for the Y mark of the test model
THEN Run the following Steps"
9 | RESTART
10 | SET_VELOCITY_LIMIT ACCEL_TO_DECEL=7000
11 | SET_PRESSURE_ADVANCE ADVANCE=0
12 | SET_INPUT_SHAPER SHAPER_TYPE=MZV
13 | TUNING_TOWER COMMAND=SET_VELOCITY_LIMIT PARAMETER=ACCEL START=1500 STEP_DELTA=500 STEP_HEIGHT=5
14 | Print the Model as above
If you see no rings add the following to the [input_shaper] section
[input_shaper]
shaper_freq_x: ... # frequency for the X mark of the test model
shaper_freq_y: ... # frequency for the Y mark of the test model
shaper_type: mzv
If you still have rings, rerun steps 9-14 and replace step 12 with:
12 | SET_INPUT_SHAPER SHAPER_TYPE=EI
If you see no rings add the following to the [input_shaper] section |  |  | and use the shaper_type that worked best for you
[input_shaper]
shaper_freq_x: ... # frequency for the X mark of the test model
shaper_freq_y: ... # frequency for the Y mark of the test model
shaper_type: el
If neither MZV or El work well consult: |  | https://www.klipper3d.org/Resonance_Compensation.html#input-shapers

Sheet: X and Y Offsets
Setting the X and Y Offsets
Video Guide
References: | https://www.klipper3d.org/Probe_Calibrate.html#calibrating-probe-x-and-y-offsets
Legend:
 | DO NOT EDIT
 | Edit to Suit
 | User Input
Steps:
1 | Navigate to Terminal in Octoprint, Mainsail, or Fluidd
2 | Issue Command:
 |  | PROBE
3 | Issue Command
 |  | GET_POSITION
4 | Record Toolhead Position
 | Toolhead X Probe | 188
 | Toolhead Y Probe | 185
5 | Mark Bed at Probe point
6 | Move Nozzle to over marked Point
7 | Issue Command
 |  | GET_POSITION
8 | Record Toolhead Position
 | Toolhead X Nozzle | 224
 | Toolhead Y Nozzle | 148
9 | Add Offsets to Printer.cfg
 | X Offset | 36.000
 | Y Offset | -37.000

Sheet: Max Volumetric Speed
Max Volumetric Speed
Video Guide
References: | https://github.com/SoftFever/OrcaSlicer/wiki/Calibration#max-volumetric-speed
Legend:
 | DO NOT EDIT
 | Edit to Suit
 | User Input
Steps:
 | 1 | Open OrcaSlicer
 | 2 | Go to "Calibration" -> "More..." -> "Max Flowrate
 | 3 | Fill out "Max volumetric speed test" dialog
 | 4 | Print Model
 | 5 | Measure with Calipers to spot on model before the print starts to fail
 | 4 | Paste Max Flow Value into Orca Slicer Filament Section
 | max flow value = | start + (height-measured * step)
 | Max Flow Value = | Start + | (Height Measured * | step)
 | 18.615 | 5 | 27.23 | 0.5
 | 5% = | 17.68425
 | 10% = | 16.7535

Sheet: Lead Screw Rotation Distance
Lead Screw Rotation Distance
Video Guide
References: | https://www.klipper3d.org/Rotation_Distance.html#axes-with-a-lead-screw
Legend:
 | DO NOT EDIT
 | Edit to Suit
 | User Input
 | T8
 | Pitch | # of Threads
Variables | 2 | 4 | T8x8
 | 2 | 2 | T8x4
 | 2 | 1 | T8x2
Rotation Distance | = Pitch | * # of Threads
2 | 2 | 1

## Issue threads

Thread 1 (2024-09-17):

Must Home Axis First

GaborDernoczi, 2024-09-17:
Remote control issue(teamviewer):

After printing no movement possible from mainsail. Homeing process need to be done first, when the modell is already on the bed....

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

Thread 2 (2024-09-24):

Calibration - Klipper Documentation

GaborDernoczi, 2024-09-24:
https://www.klipper3d.org/Rotation_Distance.html

https://www.klipper3d.org/Probe_Calibrate.html

https://www.klipper3d.org/G-Codes.html

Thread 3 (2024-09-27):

Pencil holder

GaborDernoczi, 2024-09-27:
Basic PLA 210/50°C - 60mm/sec 10% infill density

Backside

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

Frontside

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

GaborDernoczi, 2024-10-02:
Black PLA quality: Basic PLA 210/50°C - 60mm/sec 10% infill density, Gyroid, Infill Flowrate 90%(?)

Front
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

Back
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

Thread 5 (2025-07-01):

Collision

GaborDernoczi, 2025-07-01:
Original end code before collision:

M104 S0 ;extruder heater off
M140 S0 ;heated bed heater off (if you have it)
G91 ;change to relative positionion mode
G1 E-2 F300  ;retract the filament a bit before lifting the nozzle, to release some of the pressure
G1 Z+0.5 E-5 X-20 Y-20 F9000 ;move Z up a bit and retract filament even more
G28 X0 Y0 ;move X/Y to min endstops, so the head is out of the way
G90 ;change to absolute positioning mode
G1 X5 Y200 Z50 F9000 ;use this line if you want the bed to move to the front. delete if not.
M84 ;steppers off

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

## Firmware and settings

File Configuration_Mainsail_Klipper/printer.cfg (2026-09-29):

# This file contains common pin mappings for the BigTreeTech SKR 3.
# This board can ship with one of two chips, STM32H743 or STM32H723.
# To use this config, during "make menuconfig" enable "low-level
# options", "STM32H743" or "STM32H723", "128KiB bootloader",
# and "25MHz clock".

# See docs/Config_Reference.md for a description of parameters.

##################################################################   PRINTER_2   Raspberry 4 & SKR3  ##############################################################


[include mainsail.cfg]

[mcu]
serial: /dev/serial/by-id/usb-Klipper_stm32h743xx_38003A001751313238353730-if00

[stepper_x]
step_pin: PD4
dir_pin: !PD3
enable_pin: !PD6
microsteps: 16
rotation_distance: 40
endstop_pin: ^!PC1
position_endstop: 0
position_max: 300
homing_speed: 50

[stepper_y]
step_pin: PA15
dir_pin: PA8
enable_pin: !PD1
microsteps: 16
rotation_distance: 40
endstop_pin: ^!PC3
position_endstop: 0
position_max: 300
homing_speed: 50

[stepper_z]
step_pin: PE2
dir_pin: !PE3
enable_pin: !PE0
microsteps: 16
rotation_distance: 8
endstop_pin: probe:z_virtual_endstop #^!PC0
#position_endstop: 0.0
position_max: 300
#position_min: -0.5

[extruder]
step_pin: PD15
dir_pin: PD14
enable_pin: !PC7
microsteps: 16
rotation_distance: 35.845
nozzle_diameter: 0.400
filament_diameter: 1.750
max_extrude_only_distance: 150
heater_pin: PB3
sensor_type: EPCOS 100K B57560G104F
sensor_pin: PA2
#control: pid
#pid_Kp: 18
#pid_Ki: 0.8
#pid_Kd: 160
min_temp: 10
max_temp: 250
# Kell a 100 mm-es extruder kalibraciohoz (alapertek csak 50 mm)
max_extrude_only_distance: 150
# Sarok-megfolyas ellen. Direct drive kiindulas ~0.03-0.08, Bowden ~0.4-0.8.
# Kalibralas utan (SET_PRESSURE_ADVANCE teszt) ird at!
pressure_advance: 0.05
pressure_advance_smooth_time: 0.040

#[extruder1]
#step_pin: PD11
#dir_pin: PD10
#enable_pin: !PD13
#heater_pin: PB4
#sensor_pin: PA3
#...

#[verify_heater extruder]
#max_error: 120
#check_gain_time: 50
#hysteresis: 2
#heating_gain: 1

[heater_bed]
heater_pin: PD7
sensor_type: Generic 3950
sensor_pin: PA1
#control: watermark
min_temp: 5
max_temp: 130

[fan]
pin: PB7   #model cooler part-fan

[heater_fan fan]
pin: PB6   #ALU block cooler fan1

[heater_fan fan2]
pin: PB5  #ALU block cooler fan2

[printer]
kinematics: cartesian
max_velocity: 300
max_accel: 1500
max_z_velocity: 5
max_z_accel: 100

[bltouch]
sensor_pin: ^PC13  
control_pin: PE5
pin_move_time: 0.7
x_offset: -30
y_offset: -25
#z_offset: 2.2

samples: 2
samples_result: average
samples_tolerance: 0.05
samples_tolerance_retries: 3

[safe_z_home]
home_xy_position: 150,150   # bed közepe (300x300-nál ez tökéletes)
speed: 20
z_hop: 10
z_hop_speed: 5

[bed_mesh]
mesh_min: 35, 35
mesh_max: 255, 255
probe_count: 5,5
algorithm: bicubic
speed: 80
horizontal_move_z: 5
fade_start: 1
fade_end: 10

########################################
# EXP1 / EXP2 (display) pins
########################################

[board_pins]
aliases:
    # EXP1 header
    EXP1_1=PC5, EXP1_3=PB1, EXP1_5=PE9,  EXP1_7=PE11, EXP1_9=<GND>,
    EXP1_2=PB0, EXP1_4=PE8, EXP1_6=PE10, EXP1_8=PE12, EXP1_10=<5V>,
    # EXP2 header
    EXP2_1=PA6, EXP2_3=PE7, EXP2_5=PB2, EXP2_7=PC4,   EXP2_9=<GND>,
    EXP2_2=PA5, EXP2_4=PA4, EXP2_6=PA7, EXP2_8=<RST>, EXP2_10=<NC>

# See the sample-lcd.cfg file for definitions of common LCD displays.

########################################

# TMC2209 configuration

[tmc2209 stepper_x]
uart_pin: PD5
run_current: 0.800
#diag_pin:

[tmc2209 stepper_y]
uart_pin: PD0
run_current: 0.800
#diag_pin:

[tmc2209 stepper_z]
uart_pin: PE1
run_current: 0.800
#diag_pin:

[tmc2209 extruder]
uart_pin: PC6
run_current: 0.600
#diag_pin:

#[tmc2209 extruder]
#uart_pin: PD12
#run_current: 0.600
#diag_pin:

########################################
# TMC2130 configuration
########################################

#[tmc2130 stepper_x]
#cs_pin: PD5
#spi_software_miso_pin: PE15
#spi_software_mosi_pin: PE13
#spi_software_sclk_pin: PE14
#run_current: 0.800
#stealthchop_threshold: 999999
#diag1_pin: PC1

#[tmc2130 stepper_y]
#cs_pin: PD0
#spi_software_miso_pin: PE15
#spi_software_mosi_pin: PE13
#spi_software_sclk_pin: PE14
#run_current: 0.800
#stealthchop_threshold: 999999
#diag1_pin: PC3

#[tmc2130 stepper_z]
#cs_pin: PE1
#spi_software_miso_pin: PE15
#spi_software_mosi_pin: PE13
#spi_software_sclk_pin: PE14
#run_current: 0.650
#stealthchop_threshold: 999999
#diag1_pin: PC0

#[tmc2130 extruder]
#cs_pin: PC6
#spi_software_miso_pin: PE15
#spi_software_mosi_pin: PE13
#spi_software_sclk_pin: PE14
#run_current: 0.800
#stealthchop_threshold: 999999
#diag1_pin: PC2

#[tmc2130 extruder1]
#cs_pin: PD12
#spi_software_miso_pin: PE15
#spi_software_mosi_pin: PE13
#spi_software_sclk_pin: PE14
#run_current: 0.800
#stealthchop_threshold: 999999
#diag1_pin: PA0

#*# <---------------------- SAVE_CONFIG ---------------------->
#*# DO NOT EDIT THIS BLOCK OR BELOW. The contents are auto-generated.
#*#
#*# [stepper_z]
#*# position_endstop = 0.300
#*#
#*# [bltouch]
#*# z_offset = 2.272
#*#
#*# [bed_mesh default]
#*# version = 1
#*# points =
#*# 	-0.126250, -0.031250, 0.051250, -0.012500, -0.118750
#*# 	-0.208750, -0.057500, 0.028750, -0.052500, -0.142500
#*# 	-0.245000, -0.048750, 0.063750, 0.000000, -0.101250
#*# 	-0.248750, -0.067500, 0.086250, 0.040000, 0.013750
#*# 	-0.361250, -0.037500, 0.070000, 0.072500, 0.007500
#*# x_count = 5
#*# y_count = 5
#*# mesh_x_pps = 2
#*# mesh_y_pps = 2
#*# algo = bicubic
#*# tension = 0.2
#*# min_x = 35.0
#*# max_x = 255.0
#*# min_y = 35.0
#*# max_y = 255.0
#*#
#*# [extruder]
#*# control = pid
#*# pid_kp = 18.009
#*# pid_ki = 0.527
#*# pid_kd = 153.980
#*#
#*# [heater_bed]
#*# control = pid
#*# pid_kp = 72.166
#*# pid_ki = 1.449
#*# pid_kd = 898.468

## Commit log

2025-02-20 Ideamaker printer profile
2025-04-20 STL files
    [Dobókocka_sides_6_standard.stl, Téglalap.stl, phone_tablet_stand_shorter_-_32mm_cable.stl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]
2025-04-27 test and prifile
    [First_Layer_Test.stl]
2025-04-27 Files mod
    [Phone_Stand_02_telótartó OK design.stl]
2025-05-26 NY logo
    [New_York_Yankee_Logo.stl, New_York_Yankee_Logo_flat.stl]
2025-07-09 3d Parts
    [Garmin_Watch_Stand.stl]
2025-08-13 montain napkin holder
    [p2_Mountain_napkin_holder.stl]
2025-08-27 Napkin holder
    [Napkin_Holder.stl]
2025-08-29 kobra camera
    [Kobra3_Camera1.stl, Kobra3_Camera2.stl, Kobra3_Camera3.3mf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]
2025-10-31 Calibration cube
2025-11-12 extruder spacer
    [BL touch Anet__A8_Version.stl, BL_touch_Anet_A8_plus_mount_remix.stl, anet_extruder_tavtarto_63mm.stl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]
2025-12-06 circuit braker filler
2026-02-05 3D touch wiring picture
2026-02-05 3d touch
    [printer.cfg]
2026-02-06 3d touch
    critical pc13 setup
    TESTZ command not working
    connector of the 3d touch weak on SKR3 board
    [printer.cfg]
2026-02-08 Wall calibration cube
    [BRG_Calibration_Cubes.STL, Calibration_Cubes.STL, FlowCalibrationCube4mm_nozzle0.8walls.stl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]
2026-02-10 flowcalibration cube
2026-07-26 coffee drip
    [Drip+Tray+-+180x150mm.3mf]
